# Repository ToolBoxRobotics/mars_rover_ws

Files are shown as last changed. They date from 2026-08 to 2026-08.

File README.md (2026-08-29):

# Mars Rover — ROS 2 Humble Workspace

A 6-wheel, 4-corner-steering Mars exploration rover (Opportunity-style
rocker-bogie steering geometry) with a 5-axis arm, a microscope module
at the 3rd wrist joint, a full sensor suite, Xbox 360 teleop, and a
browser-based ground control console.

**This workspace was rebuilt from scratch** against a new, simplified
hardware spec. It intentionally does not carry over assumptions from
any earlier iteration of this project (e.g. the main perception camera
is now a plain USB/OpenCV webcam per the current spec, not the
previously-selected depth camera — see `rover_description`).

Host OS: Ubuntu 22.04.5 LTS · ROS 2 Humble.

Three documents, three different jobs: **this README** is the
engineering reference (architecture, design decisions, why things are
built the way they are); **`docs/INSTALL.md`** is the one-time
from-scratch build and bring-up guide; **`docs/USER_MANUAL.md`** is
the day-to-day operating guide for a rover that's already built and
running — start-up, driving, arm/mast/microscope controls, and what
the telemetry means.

## Hardware topology

| Board / device | Connects | Controls | ROS package |
|---|---|---|---|
| Arduino Mega #1 | `/dev/rover/base` | 6x drive motor (2x with encoders - see Navigation below), 3x DRI0002 Dual H-Bridge V1.4 (L298N) driver, 4x steering servo via PCA9685 (I2C, address 0x40 - factory default, deliberately unjumpered), 2x FZ0430 voltage sensor (drive rail on A0, steering rail on A1), DS18B20 temperature sensor (1-Wire, pin A4), cooling fan (MOSFET driver module, hardware PWM, pin 44, automatic/thermostatic) | `rover_base` |
| Arduino Mega #2 | `/dev/rover/arm` | 5x NEMA17 + EBA-17-M planetary gearbox (120:1); J1-J3 TB6600, J4-J5 A4988; 5x calibration switch (per-joint configurable homing direction/order/offset - see "Explicit assumptions"); FZ0430 voltage sensor (A0); DS18B20 temperature sensor (1-Wire, pin 20); cooling fan (MOSFET driver module, hardware PWM, pin 44, automatic/thermostatic); latching emergency stop and 3 predefined poses (initial/transport/service) | `rover_arm` |
| Arduino Uno #3 | `/dev/rover/mast` | 2x NEMA17 head yaw/pitch (TB6600 driver, + calibration switches), DC lift (HW-039 driver, erect/stow), 2x lift limit switch, FZ0430 voltage sensor (A0), DS18B20 temperature sensor (1-Wire, pin A4), cooling fan (MOSFET driver module, software PWM, pin A2, automatic/thermostatic) | `rover_mast` |
| Arduino Uno #4 | `/dev/rover/microscope` | DRV8825 + 24BYJ-48 focus/zoom stepper (4-wire bipolar wiring), dimmable LED, SG90 lens cover, DS18B20 temperature sensor (1-Wire, pin 11), cooling fan (MOSFET driver module, hardware PWM, pin 3, automatic/thermostatic) | `rover_microscope` |
| Arduino Uno #5 | `/dev/rover/antenna` | 2x NEMA17 + EBA-17-M planetary gearbox (120:1) + TB6600, high-gain-antenna gimbal (azimuth G1 + elevation G2), 2x calibration switch, FZ0430 voltage sensor (A0), DS18B20 temperature sensor (1-Wire, pin A4), cooling fan (MOSFET driver module, hardware PWM, pin 9, automatic/thermostatic) | `rover_antenna` |
| Arduino Uno #6 | `/dev/rover/power` | 2x INA226 voltage+current monitor (one per 24V battery, behind a TCA9548A I2C mux, A4/A5 - see "Explicit assumptions" for why the mux is needed and a real caveat about current-reading accuracy), DS18B20 temperature sensor (1-Wire, pin 2, monitors the onboard computer, not this board's own enclosure), cooling fan for that computer (MOSFET driver module, hardware PWM, pin 3, automatic/thermostatic). Telemetry-only - no command message, this board controls nothing an operator sends it | `rover_power` |
| Microscope USB camera | `/dev/rover/microscope_cam` | live view, snapshot, recording | `rover_microscope` |
| Main USB camera | `/dev/rover/main_cam` | forward perception (OpenCV) | `rover_sensors` |
| BNO086 IMU (SparkFun Qwiic breakout, UART-RVC jumper mode) | `/dev/rover/imu` (Waveshare USB-TTL (B), CH343G) | orientation + accel, **no Arduino** | `rover_sensors` |
| Waveshare L76X GPS | `/dev/rover/gps` (USB, NMEA0183) | position/velocity, **no Arduino** | `rover_sensors` |
| RPLIDAR C1 | `/dev/rover/lidar` | 360° scan for autonomous nav | external `rplidar_ros` (or `sllidar_ros2`) |
| Xbox 360 controller | USB/wireless receiver | mode-switched drive/arm/mast/microscope teleop | `rover_teleop` (on top of `joy`) |

The last five rows need no Arduino at all — the IMU and GPS modules
free-run straight to a USB-serial adapter, the cameras are plain
UVC/OpenCV devices, and the LIDAR ships its own ROS driver.

All nine serial/video devices are referenced by the stable
`/dev/rover/*` names above; see `rover_bringup/config/udev/99-rover-serial.rules`
for the udev rules that create them, and `tools/identify_rover_devices.py`
for generating them interactively from your own hardware rather than
hand-editing placeholders (including an important caveat about the
three Mega 2560 boards possibly sharing an identical or empty USB
serial number).

These show pin groupings and counts, not exact per-pin schematics —
cross-reference the exact pin constants in each board's `.ino` file
(linked from the hardware topology table above) before wiring, and see
that same file's header comment for power-supply notes (the DRI0002
logic-jumper caveat, servo power needing a separate 5-6V rail, the
lift motor's different dual-direction-pin H-bridge convention) that
don't fit in a pin-level diagram.

## Package map

```
src/
  rover_protocol/     shared checksummed serial framing + SerialLink, used by every bridge
  rover_msgs/         custom interfaces (Base/Arm/Mast/Microscope/Antenna Command+State, BoardStatus, DriveMode) + HomeJoint.srv
  rover_description/  URDF/xacro model (chassis, arm, mast, sensors, solar panels, antenna) + RViz display launch
  rover_base/         Mega #1 bridge: cmd_vel -> 4-corner-steering kinematics -> serial, + wheel odometry
  rover_arm/          Mega #2 bridge: joint-space ArmCommand -> serial, calibration homing, MoveIt trajectory bridge
  rover_arm_moveit_config/ MoveIt2 planning config for the 5-axis arm (SRDF, kinematics, OMPL, controllers)
  rover_mast/         Uno #3 bridge: pan/tilt head (calibration homing) + erect/stow lift -> serial
  rover_microscope/   Uno #4 bridge + USB camera publisher w/ snapshot & recording services
  rover_antenna/      Uno #5 bridge: 2-axis (azimuth/elevation) HGA gimbal -> serial
  rover_sensors/      BNO086 (UART-RVC) IMU driver, L76X GPS driver, main camera publisher
  rover_teleop/       Xbox 360 -> drive/arm/mast/microscope command mapping (built on `joy`)
  rover_web_gui/      FastAPI + WebSocket ground control console (see below)
  rover_navigation/   SLAM (slam_toolbox), sensor fusion + GPS (robot_localization), Nav2 config and launch files
  rover_bringup/      top-level launch file, udev rules, serial-port config
firmware/
  common/RoverProtocol/  Arduino-side counterpart to rover_protocol (install as a library)
  base_mega1/            base_mega1.ino
  arm_mega2/              arm_mega2.ino
  mast_uno3/             mast_uno3.ino
  microscope_uno4/       microscope_uno4.ino
tools/
  validate_workspace.py     syntax/parse sweep (Python/XML/YAML/JS/brace-balance/msg) over the whole tree
  identify_rover_devices.py interactive udev VID:PID/serial capture -> generates 99-rover-serial.rules
  raw_serial_probe.py       ROS-free probe: does a board reply to a raw frame at all? (bypasses rclpy/SerialLink)
```

## Base drive modes

The base supports three steering-geometry modes, selected via
`rover_msgs/DriveMode` on the `rover_base/drive_mode` topic (default
ACKERMANN if nothing has been received yet). `geometry_msgs/Twist` on
`cmd_vel` is reinterpreted differently depending on which mode is
active — see `rover_base/rover_base/kinematics.py` for the exact math.

| Mode | Twist fields used | What it does |
|---|---|---|
| `ACKERMANN` (0) | `linear.x`, `angular.z` | Normal driving — exact ICR-tangent corner steering, front/rear pairs mirror for coordinated arcs |
| `POINT_TURN` (1) | `angular.z` only | Rotate about the rover's own center — forward component forced to zero |
| `STOP` (2) | none (Twist ignored) | Unconditional zero throttle, centered steering |

Both from the Xbox controller (in DRIVE subsystem mode: **X** toggles
ACKERMANN↔POINT_TURN, **Y** forces STOP immediately — see
`rover_teleop/config/xbox_teleop.yaml`) and from the web GUI (mode
buttons at the top of the DRIVE panel, plus a draggable on-screen
joystick for proportional control — see `static/app.js`) publish to
the same topic, so either can drive and either can see what mode is
currently active (`rover_base/command_echo`'s `drive_mode` field is
the ground truth, which both the web GUI's telemetry and — if you
build one — any autonomy stack should read rather than assume).
Both input devices scale stick/joystick deflection by the same
`max_linear_mps`/`max_angular_radps`/`deadzone` values, loaded from
one shared file (`rover_teleop/config/drive_sensitivity.yaml`) rather
than two separately hardcoded copies — see `docs/INSTALL.md` Section
9.4 for how to tune them.

**Hardware caveat, not a bug** (documented in detail as a code comment
on `point_turn_wheel_commands()`): POINT_TURN is bounded by the same
±60° servo limit as ACKERMANN corner steering, so it can't reach a
perfect zero-radius pivot for wheels close to the vehicle's center
(the real angle needed there exceeds 90°) — the achieved motion is the
closest approximation the hardware allows, same limitation already
noted for ACKERMANN's own point-turn-via-zero-forward-velocity case.

## Navigation (SLAM + Nav2 + sensor fusion)

Wheel odometry, IMU/encoder fusion (`robot_localization`), GPS
conversion services, SLAM (`slam_toolbox`), and autonomous navigation
(Nav2) are all wired together. Sensor fusion runs unconditionally as
part of normal bringup (it strictly improves what SLAM/Nav2 already
consume); SLAM and Nav2 navigation are both off by default and
mutually exclusive with each other — build a map first, then navigate
against it, not both at once.

### Architecture

```
encoders (ML, MR) ──┐
                     ├─→ rover_base/odometry_node ─→ wheel_odom ──┐
IMU (BNO086) ────────┼──────────────────────────────────────────┤
                     │                                            ├─→ local EKF ─→ odom (TF: odom → base_link)
                     └────────────────────────────────────────────┘
GPS (L76X) ──→ navsat_transform_node ──→ /odometry/gps (telemetry) + /fromLL, /toLL (services)

slam_toolbox (mapping) or AMCL (navigating) ─→ TF: map → odom
```

- **Wheel odometry** (`rover_base/odometry_node`) reads only the two
  fixed middle wheels (ML/MR) — the only pair whose rolling axis never
  changes with corner steering. See `rover_base/rover_base/odometry.py`'s
  module docstring for the full reasoning. It no longer broadcasts any
  TF itself; it feeds the EKF instead (see below).
- **Local EKF** (`robot_localization`'s `ekf_node`, `rover_navigation/config/ekf_local_params.yaml`)
  fuses that wheel odometry with the BNO086 IMU and becomes the sole
  publisher of the `odom → base_link` TF — smoother and more accurate
  than either sensor alone, which directly improves slam_toolbox's
  scan matching and Nav2's local costmap. Fusion fields are matched
  to what each sensor actually measures rather than a generic
  "fuse-everything" template: wheel odometry contributes velocity
  only (not its own heading estimate, so the IMU's independently
  measured heading corrects drift instead of reinforcing the same
  error twice); the IMU contributes yaw and linear acceleration but
  **not** roll/pitch (redundant under `two_d_mode`, which already
  constrains the filter's own state to zero regardless) or angular
  velocity (the BNO086 in UART-RVC mode doesn't provide it — see
  `bno086_rvc_node.py`).
- **GPS** (`navsat_transform_node`, `rover_navigation/config/navsat_transform_params.yaml`)
  deliberately does **not** feed a second, GPS-fusing "global" EKF —
  that's the common `robot_localization` pattern for outdoor robots,
  but it would fight slam_toolbox/AMCL for ownership of the
  `map → odom` TF (both would try to publish the same edge). Instead
  GPS is used two conflict-free ways: telemetry (`/odometry/gps`, a
  Cartesian rendering of "where GPS thinks the rover is," useful to
  log/compare against the SLAM-based estimate) and **GPS waypoint
  goals** — `rover_navigation/scripts/gps_goal.py` converts a lat/lon
  into the current map-frame position via the `/fromLL` service, then
  sends that straight to Nav2's `navigate_to_pose` action. Nav2 and
  AMCL never need to know GPS was involved at all.
  ```bash
  ros2 run rover_navigation gps_goal.py 42.4373 -86.9436
  ```
  (Needs Nav2 already running against a saved, geo-referenced map —
  the conversion is relative to wherever the datum got set, i.e.
  wherever the rover had a GPS fix when `navsat_transform_node` first
  started.)
- `robot_state_publisher` (already running as part of normal bringup)
  fills in `base_link → ...sensor frames` from the URDF, including
  `base_link → lidar_link`. `slam_toolbox` (while mapping) or Nav2's
  AMCL (while navigating a saved map) supply the remaining
  `map → odom` link — the full chain
  (`map → odom → base_link → lidar_link`) is what lets the LIDAR's
  `/scan` data actually place obstacles on a consistent map.

### Build a map

```bash
ros2 launch rover_bringup bringup.launch.py use_slam:=true
```
Drive the rover around (Xbox teleop or the web GUI) until RViz shows a
complete map, then save it:
```bash
ros2 run nav2_map_server map_saver_cli -f ~/mars_rover_ws/src/rover_navigation/maps/my_map
```

### Navigate autonomously against that map

```bash
ros2 launch rover_bringup bringup.launch.py use_navigation:=true \
    nav_map:=$HOME/mars_rover_ws/src/rover_navigation/maps/my_map.yaml
```
Send goals from RViz (`rover_navigation/rviz/navigation.rviz` has the
"2D Pose Estimate" and "Nav2 Goal" tools already added), via
`ros2 action send_goal /navigate_to_pose ...`, or by GPS coordinate
with `gps_goal.py` above.

### Dependencies

Not vendored in this workspace — see `docs/INSTALL.md`:
`slam_toolbox`, `navigation2`, `nav2_bringup`, `robot_localization`,
`geographic_msgs`. `slam_toolbox`/`navigation2`/`nav2_bringup` are
only actually required at runtime if you pass `use_slam:=true` or
`use_navigation:=true`; `robot_localization` and `geographic_msgs` are
needed unconditionally, since sensor fusion always runs.
`rover_navigation` itself (a lightweight config/launch/scripts-only
package) is always present.

### Not tuned for your environment

`rover_navigation/config/nav2_params.yaml` ships with standard,
reasonable starting values (footprint sized to the rover's actual
wheel extents, velocity limits matching `rover_base`), not something
pre-tuned against your specific space. `ekf_local_params.yaml`'s
process noise covariance is `robot_localization`'s own published
default, not independently re-derived; the measurement covariance
`rover_base/odometry_node.py` publishes on its wheel odometry
(`_TWIST_VARIANCE_*`) is a reasonable placeholder in the same spirit,
not characterized against this rover's actual encoders. Expect to
adjust all three after watching the rover drive and navigate a few
times.

## Arm motion planning (MoveIt2)

Task-space planning for the 5-axis arm (drag an interactive marker to
a target pose, plan a collision-aware path, execute it) via MoveIt2,
off by default (`use_moveit:=false`).

### Architecture

```
RViz "MotionPlanning" panel / any MoveGroupInterface client
        │  plans against the SRDF's "arm" group (shoulder_yaw..wrist_roll)
        ▼
move_group (rover_arm_moveit_config)
        │  planned trajectory (radians), via the FollowJointTrajectory action
        ▼
arm_controller/follow_joint_trajectory ─ rover_arm's trajectory_action_server
        │  converts each waypoint: radians → steps (joint_conversion.py),
        │  reorders to this rover's own joint order (MoveIt doesn't
        │  guarantee its joint_names arrives in that order)
        ▼
ArmCommand (joint_target_steps) ─ exactly what teleop/manual control already sends
        ▼
rover_arm_bridge → 'A' frame → arm Mega #2 → AccelStepper per joint
```

`rover_arm_bridge` and the firmware never change: MoveIt's trajectories
arrive as ordinary `ArmCommand` messages indistinguishable from
teleop's. The bridge between the two — `rover_arm`'s
`trajectory_action_server` — exists specifically because the firmware
already does its own velocity/acceleration profiling on-device
(`AccelStepper`); writing a full `ros2_control` hardware interface
just to satisfy MoveIt's usual execution path would mean reimplementing
that. `moveit_simple_controller_manager`'s `FollowJointTrajectory`
support is built for exactly this case — a robot controller that
already speaks that action interface directly.

Each waypoint is sent as an absolute joint-space target and the bridge
waits until the arm's within tolerance (`goal_tolerance_rad`, default
0.02) or the waypoint's planned time has elapsed, whichever comes
first, before advancing — not a precise replication of MoveIt's planned
velocity profile. Fine for a slow, deliberate sample-inspection arm;
worth knowing if trajectory timing fidelity ever matters more than it
does here.

The `steps_per_joint_rev` calibration (`rover_arm/config/arm_topology.yaml`)
existed as declared-but-unused placeholder data (200 full steps × 1/16
microstepping × 5:1 gear = 16000) since the arm's very first build —
this is what finally puts it to use.

### Using it

```bash
ros2 launch rover_bringup bringup.launch.py use_moveit:=true
ros2 launch rover_arm_moveit_config moveit_rviz.launch.py
```
In RViz's MotionPlanning panel: drag the interactive marker at the
arm's tip to a target pose, **Plan**, check the preview, **Execute**.
Or send a named target — `home` (all-zero, matching the arm's own
homed position) is defined in the SRDF.

The arm must have finished its own startup homing sequence
(`rover_arm_bridge`'s `home_on_startup`, see "How does the calibration
homing sequence work" — `ArmState.homed`) before `trajectory_action_server`
will accept a goal at all; it rejects goals otherwise rather than
commanding an un-homed arm to a fabricated "zero" that isn't real.

### Dependencies

Not vendored — see `docs/INSTALL.md`: `ros-humble-moveit`,
`ros-humble-moveit-configs-utils`. Only required at runtime if you
pass `use_moveit:=true`; `rover_arm_moveit_config` itself (config/launch
only) is always present, matching the same pattern SLAM/Nav2 already use.

## Arm calibration

Each joint's calibration-switch homing can now be triggered on demand
— either individually or all five at once — not just automatically at
bridge startup.

### Architecture

```
Web GUI "CALIBRATE J3" button
        │  POST /api/arm/home/2
        ▼
rover_arm_bridge's rover_arm/home_joint service (rover_msgs/srv/HomeJoint)
        │  validates joint_index locally, writes a 'Z' frame with that index
        ▼
arm Mega #2 → startHoming(2) → seeks J3's limit switch, zeroes it,
              leaves J1/J2/J4/J5's homed status and position untouched
```

`HomeJoint.srv` (`int8 joint_index` in; `bool accepted` + `string
message` out) is this project's first custom service — everything
before this was messages/topics only. `joint_index=-1` homes all 5
joints in one sequential pass (the same behavior `home_on_startup`
has always triggered once at boot); `0`-`4` homes just that one joint,
leaving every other joint's calibration and position alone —
`ArmState.joint_homed` (`bool[5]`) reports this per-joint, not as one
shared flag, precisely so partial calibration is visible rather than
collapsed into a single ambiguous "homed: false".

The service reports whether the request was successfully **written**
to the serial link, not whether the firmware will act on it — that's
a real boundary, not a shortcut: this layer can't see whether the
Arduino, say, silently ignores the request because a homing run is
already in progress. `ArmState.joint_homed` (via `ros2 topic echo
/rover_arm/state` or the web GUI's per-joint ✓/✗ indicators) is the
actual source of truth for whether/when homing completed.

### Deliberate simplification: no partial-homed motion

Every joint must be individually homed — and no homing run in
progress — before **any** joint-move command is accepted, even though
homing itself is now per-joint. A command that moved only the
already-homed joints while silently ignoring the rest would let the
arm move through configurations nothing has actually verified are
safe for the not-yet-homed joint's real position; waiting for a fully
calibrated arm before accepting any motion at all is simpler and
safer. `ArmState.homed` (`bool`) is `all(joint_homed)`, computed by
`rover_arm_bridge` — not sent over the wire, and kept specifically so
MoveIt's `trajectory_action_server` (which already gated goals on this
exact field) needed no changes for this to work.

### Configurable per-joint homing direction and order

Two things about the homing process that used to be a single, uniform
assumption applied to all five joints are now independently
configurable per joint, as constants in `arm_mega2.ino` — both
currently PLACEHOLDER values matching the previous, only behavior,
pending real mechanical verification on the bench:

- **`kHomingDirection[5]`** — which way each joint's stepper seeks
  toward its own limit switch (`+1` or `-1`). Previously a single
  hardcoded `-1` applied to every joint regardless of its own actual
  mechanical layout.
- **`kHomingOrder[5]`** — the sequence joints are homed in during an
  all-5 run (`joint_index=-1`). Previously a fixed J1 → J2 → J3 → J4 →
  J5 loop with no way to change it; a permutation of 0-4, useful for a
  mechanical/safety sequence where one joint genuinely needs to home
  before another (e.g. shoulder before wrist, to avoid a collision
  partway through the sweep). Only affects the all-5 case — a
  single-joint request (0-4) always just homes that one joint,
  unaffected by this order.

Neither is sent over the wire or configurable from the web GUI —
they're physical-calibration facts about the hardware itself, set once
in firmware to match the real joints, not something an operator
chooses per homing run.

### Steps-per-degree, the real lower limit, and the operational range

What this file used to call an "offset" (`kHomingOffsetSteps` — a
small, per-joint, separately-tuned distance from an assumed-zero
switch position to a joint's true reference point) has been replaced
entirely by a physically-grounded model, not just renamed. Three new
constants, none of them invented fresh — all three sourced directly
from numbers this project had already established elsewhere:

- **`kStepsPerDegree[5]`** — derived from, and must be kept in sync
  with, `rover_arm/config/arm_topology.yaml`'s own
  `steps_per_joint_rev` (currently 384000 for all five: 200 full steps
  × 1/16 microstepping × 120:1 EBA-17-M planetary gearbox — see that
  file's own comment). 384000 / 360 ≈ 1066.667 steps/degree.
- **`kMinDeg[5]` / `kMaxDeg[5]`** — each joint's own operational range
  in degrees, relative to true center. Sourced directly from
  `rover_description/urdf/arm.xacro`'s own joint `<limit>` tags
  (shoulder_yaw/elbow_pitch: ±150°, shoulder_pitch/wrist_pitch: ±100°,
  wrist_roll: ±170°) — the same numbers MoveIt itself already plans
  against, not a separately-guessed pair.
- **`kLowerLimitSteps[5]`** — the value assigned via
  `setCurrentPosition()` the instant a joint's limit switch trips. The
  limit switch's own physical trigger point is now understood to sit
  at each joint's own operational lower bound, not at an arbitrary
  "zero" the way `kHomingOffsetSteps` treated it. PLACEHOLDER values
  currently assume the switch sits exactly at `kMinDeg[j]` (converted
  to steps, rounded) — a reasonable starting assumption, not a
  bench-verified one. Kept independently adjustable from `kMinDeg` in
  code (not derived from it), so a real mechanical safety margin
  between "where the switch actually trips" and "the joint's own
  declared operational minimum" can be introduced later without
  touching either constant's own meaning.

Once the switch trips and `kLowerLimitSteps[j]` is assigned,
`serviceHoming()`'s own two-phase state machine (`SEEKING_LIMIT` →
`MOVING_TO_CENTER`, renamed from the old model's `MOVING_TO_OFFSET`
now that the destination is always exactly 0, not a per-joint tuned
value) drives the remaining distance to absolute step 0 using the
normal accel/speed profile — 0 now means each joint's own true center,
not an arbitrary reference point. This is still the same "seek limit,
then move to a real reference position" pattern `mast_uno3.ino`'s and
`antenna_uno5.ino`'s own post-calibration sequences use, just now
landing on a physically meaningful center rather than an arbitrary
offset destination.

**Every regular joint command, and every preset move, is now clamped**
to `[kMinDeg, kMaxDeg]` (converted to steps via `kStepsPerDegree`)
before being accepted — `clampToOperationalRange()`, applied at both
call sites. This is a real, firmware-side backstop, not merely a
courtesy: since MoveIt already plans within these same limits (sourced
from the same `arm.xacro`), this should rarely if ever actually clamp
anything reaching the firmware via a MoveIt-planned trajectory — it
exists for whatever else might reach it: a raw command from the web
GUI's own sliders, a hand-typed test frame, a future client with no
knowledge of these limits at all. The web GUI's own 5 joint sliders
were updated to match these same real bounds (`±160000` / `±106667` /
`±181333` steps) as a UI-side backstop alongside the firmware's own,
replacing an old, disconnected `±16000` placeholder that turned out to
trace back to the same stale 5:1 gear-ratio assumption `arm_topology.yaml`
had already moved past.

**Keeping these numbers in sync matters for a real reason, not just
tidiness**: a mismatch between `arm.xacro`'s own limits and this
firmware's `kMinDeg`/`kMaxDeg` would mean MoveIt could plan a
trajectory this firmware's own clamp then silently truncates — the arm
would quietly stop short of where MoveIt believes it commanded it to
go. There's no automatic single source of truth across the
URDF/firmware/ROS-config/browser boundary here — `arm.xacro`'s own
`<limit>` tags, `arm_topology.yaml`'s own `steps_per_joint_rev`,
`arm_mega2.ino`'s own `kStepsPerDegree`/`kMinDeg`/`kMaxDeg`/
`kLowerLimitSteps`, and the web GUI's own slider bounds are four
separate places carrying related numbers that all need updating
together by hand if any of them ever change.

### Predefined poses

Three fixed five-joint poses — `kInitialPoseSteps`, `kTransportPoseSteps`,
`kServicePoseSteps` in `arm_mega2.ino` — each reachable with a single
`'P'` frame (`rover_arm/arm_preset` service, `rover_msgs/srv/ArmPreset`)
rather than requiring the operator to know and send all 5 target steps
by hand. All three are currently PLACEHOLDER (all-zero, every joint at
its own homed zero) pending real-world calibration — not yet claimed
to be safe, useful, or even reachable poses. Deliberately implemented
as firmware-side constants, addressable by index, rather than computed
or stored at the ROS/web-GUI layer: this way the poses stay reachable
even if the ROS stack is down but the serial link to the Arduino
itself still works, and there's exactly one place these values live
rather than a web-GUI-side copy that could drift from a firmware-side
one. Subject to the same "fully homed, not mid-homing, not e-stopped"
gate as a regular joint command — a preset move is still new movement,
no different from an operator manually driving the sliders as far as
safety gating is concerned.

The web GUI's arm panel exposes these as three buttons (`INITIAL
POSITION`, `TRANSPORT POSITION`, `SERVICE POSITION`) — this **replaced**
an existing button (`RETURN HOME`) that used to send a hardcoded
`[0,0,0,0,0]` directly as a regular joint command, rather than leave
two parallel, potentially-diverging ways to reach a default pose.

## Arm emergency stop

A latching emergency stop, triggered/cleared via a `'X'` frame
(`rover_arm/emergency_stop` service, `rover_msgs/srv/EmergencyStop`) -
`ArmState.estop_active` reports the firmware's own current state.

**Deliberately does NOT de-energize the drivers - a real safety
trade-off, not an oversight.** Conventional e-stop behavior cuts power
to the actuators; this one instead calls `AccelStepper::stop()` on
every joint (a fast, controlled deceleration using each joint's own
configured acceleration - not an instantaneous halt, since forcing an
abrupt step-rate change instead risks the motor losing synchronization
with its driver) and leaves every driver energized throughout. This is
a gravity-loaded arm: de-energizing mid-air risks an uncontrolled
drop, judged worse than holding position under load, the same
philosophy this board's own watchdog-timeout behavior already applies
(and mast/antenna's own watchdogs share).

Once triggered, the e-stop blocks every source of new movement
(regular joint commands, preset requests) until an explicit clear is
received - the firmware itself is the authoritative source of truth
for this, not the ROS bridge node upstream of it, specifically so a
bridge-node restart or hiccup after an e-stop can't silently resume
motion. The web GUI's arm panel exposes this as two buttons (`E-STOP`,
styled distinctly - a solid, high-contrast button rather than this
project's usual outline style, matching real e-stop button
conventions - and `CLEAR E-STOP`), plus a live status readout in the
telemetry panel driven by `estop_active` itself, not by which button
was last clicked - so a page reload or another operator's own action
stays in sync automatically.

### Using it

Web GUI (arm panel): `CALIBRATE J1`-`CALIBRATE J5` for a single joint,
`CALIBRATE ALL 5` for the full sequence, `INITIAL POSITION` to move to
the arm's predefined starting pose (a preset move, not a calibration
action — only meaningful once actually homed, and safely a no-op
otherwise since the firmware ignores it like any other joint command
would be). Driver enable/disable is a single toggle (label and color
both follow the firmware's own reported `drivers_enabled` state, not
a locally-tracked guess) — this brings the arm in line with the same
toggle convention the mast, antenna, and microscope panels already use
for their own driver control; the arm was the one panel still using
two separate buttons for it before this.

Directly:
```bash
ros2 service call /rover_arm/home_joint rover_msgs/srv/HomeJoint "{joint_index: 2}"   # home J3 only
ros2 service call /rover_arm/home_joint rover_msgs/srv/HomeJoint "{joint_index: -1}"  # home all 5
```

## Antenna gimbal

A 2-axis high-gain-antenna pointing mechanism, top rear left of the
rover, modeled on the real Mars Exploration Rover (Spirit/Opportunity)
HGA gimbal — G1 (azimuth, primary axis, normal to the deck) and G2
(elevation, secondary axis, parallel to the deck), with the antenna
disk on a short arm at the end and the beam radiating perpendicular to
the disk face.

### Real-hardware research behind this

The spec for this subsystem gave two different ranges per axis: G1
`[-90°, 90°]` / G2 `[90°, 270°]`, and — specifically for the
*deployed* configuration — g1 `[15°, 285°]` / g2 `[0°, 180°]`
("software-limited"). Those two pairs don't reconcile numerically as a
simple offset (180° span vs. 270° span for azimuth), so before
building anything, this was checked against the real MER HGAG
engineering paper (Sokul et al., ESMATS 2004) rather than guessed at.
That paper confirms the real mechanism: a pyrotechnic-released,
one-way spring-gate deployment (the drive "can no longer return to the
original stowed position" once through the gate), with **280° azimuth
and 234° elevation** as the real, published post-deployment rotation
spans — closely corroborating g1's 270° span and confirming g2's 180°
is a deliberate *software* restriction of what's mechanically possible
(real elevation capability is 234°), matching this project's own
"software-limited" framing exactly.

**g1 `[15°, 285°]` and g2 `[0°, 180°]` are what's implemented and
enforced** (`antenna_uno5.ino`'s `constrain()` calls,
`antenna_topology.yaml`'s `min/max_azimuth_deg`/`min/max_elevation_deg`).
G1/G2 (uppercase) reads as a different reference frame — not
reconciled into a second active constraint here, since doing so would
require guessing at a transformation the source material doesn't
specify. Flagged here rather than silently picked one interpretation.

### What's modeled and what isn't

Only the two gimbal axes' *operational* range is implemented — there's
no launch-lock, pyrotechnic pin puller, or deploy-gate mechanism
modeled (out of scope for what was asked: 2 stepper axes + calibration
switches, not a deployment sequencer). The antenna is treated as
already deployed for all purposes here.

Each calibration switch is assumed mounted at that axis's own
operational **minimum** (15° azimuth, 0° elevation) — a real design
choice, not verified against an actual mechanical drawing, flagged
here and in `antenna_uno5.ino`'s header comment so it's easy to
correct against real hardware. This makes homing simpler than the
mast's: the switch position *is* each axis's minimum, not offset from
a separately-centered zero, so `setCurrentPosition()` at trigger time
directly establishes "home" — no follow-on move-to-a-different-
reference step the way the mast's own (corrected) calibration sequence
needs one.

### Hardware

Same actuator/driver combination as the arm's joints — 2x NEMA17 +
EBA-17-M planetary gearbox (120:1) + TB6600, on an Arduino Uno with 2
calibration switches and an FZ0430 voltage sensor. `steps_per_deg`
and the speed/acceleration/homing-speed constants in `antenna_uno5.ino`
are copied directly from `arm_mega2.ino` rather than re-derived — same
actuator, already-vetted numbers. The two TB6600 drivers share one
enable pin (`kGimbalEnablePin`), safe for the same reason the mast's
own two TB6600s share one: two opto-isolated ENA inputs draw
comfortably under a typical GPIO's safe sink rating, unlike the arm's
three TB6600s, which get independent pins instead.

### Using it

Web GUI (antenna panel): azimuth/elevation sliders (range fetched from
`antenna_topology.yaml` via `GET /api/config`, same mechanism the
mast's transport-position preset uses) and a `CLOSE DRIVER (ENABLE)` /
`OPEN DRIVER (DISABLE)` toggle — starts disabled after homing, same
convention as the mast, until explicitly enabled.

Xbox controller (LB until in ANTENNA mode): left stick jogs azimuth
(X) and elevation (Y) from the current position, rather than an
absolute-position mapping the way the mast's right stick works — the
antenna's operational range isn't centered around 0° the way the
mast's is, so mapping stick deflection straight to an absolute angle
would be a much less natural control feel here.

## Explicit assumptions and simplifications

These are the calls made where the spec was silent or where
"simplify" pointed toward a lighter-weight choice. Flag any of these
back if they don't match the real hardware:

- **Arm: driver-enable state is now real telemetry, not just a
  command the host remembers sending - and the web GUI's own button
  for it changed from two to one to match.** `arm_mega2.ino`'s own
  `driversEnabled` was already tracked internally; it just never made
  it into the outgoing `'S'` frame, so the only place that state
  existed was whatever the host last commanded via the `'A'` frame's
  own `enable` field. That gap was real, not hypothetical:
  `startHoming()` enables drivers automatically before seeking, with
  no operator action involved, so a value the web GUI only remembered
  sending would have silently drifted out of sync with reality the
  moment homing started on its own. Added `drivers_enabled` as a new,
  20th field on the `'S'` frame (threaded through the protocol layer,
  `ArmState.msg`, the bridge node, and the web GUI's own state dict) so
  this is now the firmware's own actual, current state, always - not a
  command echo.

  The web GUI's own two separate buttons (`ENABLE DRIVERS` /
  `DISABLE (FREE-SPIN)`) became one toggle, at the user's own explicit
  request - and this turned out to be less a departure from this
  project's own convention than a correction of one: the mast, antenna,
  and microscope panels already use a single `CLOSE DRIVER (ENABLE)` /
  `OPEN DRIVER (DISABLE)` toggle for the exact same kind of state; the
  arm was the one panel still using two separate buttons for it. Kept
  the arm's own, more explicit wording (`ENABLE DRIVERS` /
  `DISABLE DRIVERS (FREE-SPIN)`, the button's own label switching with
  the state rather than the other three panels' `CLOSE`/`OPEN`
  phrasing) since the free-spin consequence is a genuinely useful thing
  to say out loud for a 5-joint arm specifically, not just tidied away
  for consistency's sake - the toggle *mechanism* is what needed to
  match, not necessarily the exact words. The button's label and color
  both follow `data.arm.drivers_enabled` from live telemetry on every
  render, the same "driven by the firmware's own reported state, not a
  locally-tracked guess" approach already used for this panel's own
  E-STOP status readout.

  Verified this compiles cleanly against the real toolchain before
  calling it done, not just reviewed by eye: installed the actual AVR
  cross-compiler (`gcc-avr`, matching the Arduino IDE's own
  Atmel-flavored 7.3.0) plus `ArduinoCore-avr`, `AccelStepper`,
  `OneWire`, and `DallasTemperature` from their real source
  repositories, and compiled `arm_mega2.ino` with `-Wall` - zero
  errors, zero warnings, both before and after this session's own
  change to `sendStateFrame()`.

- **Arm: a physically-grounded homing/coordinate model replacing an
  arbitrary one, and a real operational-range clamp - sourced from
  numbers this project had already established, not invented fresh.**
  Full technical detail lives in "Arm calibration" above (see
  "Steps-per-degree, the real lower limit, and the operational range");
  this entry is about the sourcing decision itself, which is the part
  most worth flagging back if it's wrong.

  Rather than invent placeholder degree/range numbers the way most of
  this project's other uncalibrated constants default (all-zero, or
  "matches the previous behavior exactly"), this instead reused two
  sets of numbers this project already had on record before this
  session touched anything: `rover_arm/config/arm_topology.yaml`'s own
  `steps_per_joint_rev` (384000, already correctly reflecting the
  120:1 gearbox) for `kStepsPerDegree`, and
  `rover_description/urdf/arm.xacro`'s own joint `<limit>` tags (±150°/
  ±100°/±150°/±100°/±170°) for `kMinDeg`/`kMaxDeg` - both were real,
  specific, already-intentional values, not placeholders themselves,
  so treating them as placeholders here and inventing different
  numbers would have created a genuine inconsistency (MoveIt planning
  against one set of limits while the firmware clamped against
  another) rather than resolved one. `kLowerLimitSteps` (what the
  limit switch's own trigger point gets labeled as) uses the same
  numbers as `kMinDeg`, converted to steps, as its own placeholder -
  physically reasonable (switch mounted right at the operational
  minimum) but not itself bench-verified, and kept as an independently
  adjustable constant rather than computed from `kMinDeg` in code, so
  a real mechanical margin between the two can be introduced later
  without changing what either constant means.

  Found and fixed two genuine, unrelated staleness issues while
  sourcing these numbers, both traced to the same root: a stale 5:1
  gear-ratio assumption (200 full steps × 1/16 microstepping × 5:1 =
  16000) that predated this project's move to the real 120:1 EBA-17-M
  gearbox (384000) but was never fully swept away. `joint_conversion.py`'s
  own module docstring still cited the old 16000 figure; the web GUI's
  5 joint sliders still used a `±16000` bound that turned out to be
  exactly one motor revolution's worth of steps at that same old ratio
  - both fixed, the sliders updated to the real, `arm.xacro`-derived
  bounds (`±160000`/`±106667`/`±181333` steps) as a UI-side backstop
  alongside the firmware's own new clamp, not a replacement for it.

  A historical "Explicit assumptions" bullet from an earlier session
  (this file's own "Calibration direction, order, and post-limit-
  switch offset..." entry, further below) referenced
  `kHomingOffsetSteps` by name - since that constant no longer exists,
  updated that entry in place to redirect here rather than leave it
  factually describing code that isn't there anymore.

- **The actual root cause of base/arm never showing telemetry in the
  web GUI - found only after ruling out the firmware, the physical
  serial link, and the ROS topic layer entirely, each independently
  confirmed healthy first.** `rover_web_gui/ros_bridge.py`'s own
  `_on_base_state()`/`_on_arm_state()` callbacks converted fixed-size
  ROS array fields (`BaseState.encoder_ticks`/`encoder_delta_ticks`,
  `ArmState.joint_position_steps`/`limit_switch_triggered`/
  `joint_homed`) with a bare `list(msg.field)`. rclpy backs every
  fixed-size array message field with `numpy.ndarray` internally, so
  `list()` on one produces `numpy.int32`/`numpy.bool_` elements, not
  plain Python `int`/`bool` - and `json.dumps()` cannot serialize
  either numpy scalar type at all; it raises `TypeError` unconditionally.
  Reproduced directly, not just reasoned about: `json.dumps([numpy.int32(1)])`
  raises `TypeError: Object of type int32 is not JSON serializable`,
  confirming the mechanism exactly.

  **Why this took multiple sessions and several ruled-out hypotheses
  to actually find, rather than being obvious from the symptom
  alone:** `server.py`'s own `_telemetry_sender()` builds one combined
  snapshot for every board and serializes it in a single `json.dumps()`
  call inside one `asyncio` task, previously with no exception handling
  of its own around that call. An uncaught exception in an `asyncio`
  task doesn't crash the process - it just silently stops that task,
  logged only as "Task exception was never retrieved" server-side, with
  nothing the browser's own console would ever show (which is exactly
  why a browser dev-tools check came back completely clean - the
  failure never reached the browser to produce an error there in the
  first place). Every board's telemetry rode on that same one task and
  one combined snapshot, so base or arm's own bad array field silently
  killed telemetry for every board at once, not just its own - mast,
  microscope, antenna, and power *looked* like they still worked only
  because the browser kept displaying whatever their own last
  successfully-sent values had been, frozen, from before the task died;
  they were never actually still updating. Base and arm are also the
  *only* two boards whose own state messages contain any array field at
  all - checked directly against every board's own `.msg` file, not
  assumed - which is why this affected exactly and only those two,
  matching the actual reported symptom precisely.

  Fixed with an explicit per-element cast at both call sites
  (`[int(t) for t in ...]`, `[bool(t) for t in ...]`) rather than a
  generic serialization workaround, matching the same fix already
  applied once before to this exact bug class in a different file
  (`arm_bridge_node.py`'s own `_on_timer()`, from an earlier session) -
  a second, independent occurrence of the same underlying rclpy
  behavior, not a regression of the first fix. Also hardened
  `_telemetry_sender()` itself with its own per-tick exception handling
  around the send, specifically so a future, different field with the
  same problem can't silently take down every board's telemetry again
  the same way - it now logs clearly and skips that one tick instead of
  dying for the rest of the connection's lifetime.

- **A real, project-wide bug found via a live log capture, not code
  review: `SerialLink` could hang a bridge node's entire executor
  thread indefinitely on a single write, with no error and no further
  log output at all.** `rover_protocol/serial_link.py`'s underlying
  `serial.Serial` connection was constructed with a read `timeout`
  but no `write_timeout` - pyserial's own default when that's left
  unset is `None`, meaning a write blocks forever if the OS-level
  output buffer fills and the board on the other end isn't draining
  its own serial RX fast enough to keep up. This is shared
  infrastructure every bridge node (base, arm, mast, microscope,
  antenna, power) is built on, so the exposure was project-wide, not
  specific to any one board - but the arm was the one that actually
  hit it during testing, and for a specific, identifiable reason: its
  homing sequence legitimately runs far longer than this project's
  usual command-response turnaround (a 120:1 gearbox slows real joint
  motion, and `serviceHoming()`'s own seek phase doesn't yield back to
  frame handling as promptly as a quick command-and-respond cycle
  does), during which the bridge node's own continuous, periodic
  writes kept arriving while the firmware wasn't getting back around
  to draining its input quickly enough - eventually filling the
  board's tiny 64-byte hardware RX buffer and blocking the write call
  forever.

  **Diagnosed from an actual log capture, after code review alone had
  been exhausted without finding it** - a user-provided log showed the
  arm bridge node logging "sent homing request to arm Mega" and then
  going completely silent forever, no error, no crash, no further
  output of any kind - the exact signature of a thread stuck on a
  blocking syscall, not a program error, which produces neither. Since
  `_publish_status()` sits after the write call in the same function,
  a hung write there meant `BoardStatus` was never published even
  once - explaining a status lamp stuck at its default "never
  received" state (which reads as red) rather than a lamp that turns
  green and then goes stale, and why the arm specifically was the
  board most likely to actually trigger this given its own homing
  duration, even though the underlying vulnerability was never
  arm-specific at all.

  Fixed with a bounded `write_timeout` (defaulting to 0.2s, matching
  the existing read timeout's own general magnitude) threaded through
  `SerialLink`'s constructor to the underlying connection - a write
  that can't complete now raises `serial.SerialTimeoutException`,
  caught by the same exception handler every other write failure
  already goes through, rather than hanging the calling thread
  indefinitely. Verified every one of the six bridge nodes constructs
  `SerialLink` using keyword arguments exclusively before considering
  this fix backward-compatible - none needed any changes themselves,
  since a purely-keyword call site can't be affected by a new
  parameter's position in the signature. Two dedicated regression
  tests confirm `write_timeout` is actually threaded through to the
  underlying connection, not just accepted and silently dropped, and
  that it defaults to a real, bounded value rather than the `None`
  that was the root cause here.

- **Arm: a latching emergency stop, and calibration made independently
  configurable per joint where it used to be a single hardcoded
  assumption applied to all five.** Also found and fixed a real
  documentation gap while updating this table: the arm's own cooling
  fan (present in firmware for several sessions) had never made it
  into this hardware topology row at all.

  **Emergency stop deliberately does NOT de-energize the drivers - a
  real, non-obvious safety trade-off, not an oversight.** Conventional
  e-stop behavior cuts power to the actuators; this one instead calls
  AccelStepper's own `stop()` on every joint (a fast, controlled
  deceleration using that joint's own configured acceleration, not an
  instantaneous halt - forcing an abrupt step-rate change instead
  risks the motor losing synchronization with its driver, arguably a
  worse outcome than a fast but controlled stop) and leaves every
  driver energized throughout. This is a gravity-loaded arm: de-
  energizing mid-air risks an uncontrolled drop, which this project has
  already judged worse than holding position under load in the
  near-identical watchdog-timeout situation this same board's firmware
  already had (and mast/antenna's own watchdogs share the same
  philosophy). Once triggered, the e-stop is latching and blocks every
  source of new movement (regular joint commands, preset requests)
  until explicitly cleared - the firmware itself is the authoritative
  source of truth for this state, not the ROS bridge node upstream of
  it, specifically so a bridge-node restart or hiccup after an e-stop
  can't silently resume motion.

  **Calibration direction and order are now independently configurable
  per joint, as PLACEHOLDER firmware constants** (`kHomingDirection`,
  `kHomingOrder` in `arm_mega2.ino`) pending real mechanical
  verification on the bench - each currently set to match the
  previous, only behavior (uniform direction, sequential J1-J5 order)
  rather than a guessed-at "improved" default.

  **UPDATE (later session): the post-limit-switch "offset" this bullet
  originally described here has since been replaced entirely, not
  merely adjusted** - `kHomingOffsetSteps` no longer exists.
  `kLowerLimitSteps`, `kMinDeg`/`kMaxDeg`, and `kStepsPerDegree` took
  its place, along with a firmware-side clamp on every joint command
  and preset move - see "Steps-per-degree, the real lower limit, and
  the operational range" above for the complete, current model; not
  duplicated here to avoid two descriptions drifting apart from each
  other over time.

  **Three predefined poses (initial/transport/service), reachable via
  a new firmware-level command, not just a web-GUI convenience.** All
  three are ALL-PLACEHOLDER (all-zero, every joint at its own homed
  zero) pending real-world calibration - not claimed to be safe,
  useful, or even reachable poses yet. Deliberately implemented as
  fixed constants in `arm_mega2.ino` itself, addressable by index over
  the wire, rather than joint angles computed or stored at the ROS/
  web-GUI layer - this way the poses stay reachable even if the ROS
  stack is down but the serial link to the Arduino itself still works,
  and there's exactly one place these values live rather than a
  web-GUI-side copy that could drift from a firmware-side one. This
  **replaced, rather than duplicated, an existing endpoint**: the web
  GUI already had a "RETURN HOME" button sending a hardcoded
  `[0,0,0,0,0]` directly - upgraded to call the new firmware-owned
  INITIAL preset instead of leaving two parallel, potentially-
  diverging ways to reach a default pose. The "SERVICE" pose's actual
  intended purpose (what it needs to clear or reach) wasn't specified
  further when this was added - kept as a generically-named preset
  pending that detail, rather than guess at a real value without
  knowing what it's actually for.

- **Microscope: the LED/cover "protect the optics" fail-safe is
  removed entirely, at the user's own explicit request - a genuine
  safety trade-off, not a cosmetic change, worth stating plainly
  rather than folding into a routine changelog line.** Two
  independent implementations of the same behavior existed - the
  firmware's own watchdog (`microscope_uno4.ino`'s `loop()`, forcing
  the LED off and the cover closed whenever no command had arrived
  for over a second) and the bridge node's own parallel version at
  the ROS layer (`microscope_bridge_node.py`'s `_on_timer()`, forcing
  the same values into every command frame it sent whenever the ROS
  command stream itself went stale) - both found and removed
  together; removing only one would have left the other silently
  reintroducing the exact behavior being removed; the firmware has no
  way to distinguish a genuine operator command from the bridge
  node's own override.

  **What this actually means**: the LED and cover now stay in
  whatever state they were last explicitly commanded to,
  indefinitely, even if the serial link between the bridge node and
  the Uno drops, or the ROS command stream from the web GUI stops
  entirely. Previously, either kind of link loss would have
  automatically turned the LED off and closed the cover within about
  a second. **If the LED is left on or the cover left open when a
  link drops now, nothing in this software will turn it off or close
  it on its own** - that's on the operator (or whatever's upstream)
  to notice and handle. The focus stepper was never part of this
  fail-safe either way - it already just holds its last commanded
  position on a dropped link, with no separate timeout logic of its
  own, unaffected by this change.

  Removed cleanly, not just disabled: `kWatchdogTimeoutMs`/
  `lastCommandMillis` in the firmware, `command_timeout_sec`/
  `_last_command_time` (and the now-unused `time` import) in the
  bridge node, and the `command_timeout_sec` config parameter in
  `microscope_topology.yaml` are all gone, not left declared-but-
  unused - a note in that yaml file explains the parameter's absence
  explicitly, since every other board's own config still has one and
  its absence here could otherwise look like an oversight rather than
  a deliberate choice.

- **Microscope: most of a multi-part request turned out to already be
  done, verified rather than assumed.** Asked for: remove ServoEasing
  from the cover servo, add explicit OPEN/CLOSE cover buttons, add
  explicit LED ON/OFF buttons, and express LED dimming in 0-5V rather
  than raw PWM. Checked the actual current state of each part before
  doing any work rather than trust memory of what had been built: the
  ServoEasing removal (firmware header explicitly records it as
  already done "at the user's own request"), the cover buttons, and
  the LED on/off buttons were all already fully implemented and wired
  up, in both `app.js` and `index.html`. Only the 0-5V display change
  was genuinely outstanding.

  **The LED change is display-only, not a wire-protocol or hardware
  change** - the microscope's LED is still driven by plain
  `analogWrite()` PWM (0-255 duty cycle), not a true analog output or
  DAC; nothing in the request mentioned new hardware to enable one.
  0-255 duty cycle on a 5V logic pin genuinely *is* 0-5V of effective
  average output, so relabeling the existing range this way is
  accurate, not approximate. Changing the wire protocol itself to
  carry millivolts would have meant a firmware-side conversion back to
  PWM for no real gain, and could misleadingly imply a precision the
  hardware doesn't actually have - so `led_pwm` stays exactly what it
  was (0-255) all the way from the slider's own raw value through the
  wire protocol to `analogWrite()`; only the label the operator sees
  changed, via a small shared `formatLedVoltage()` helper used
  consistently by the slider, both buttons, and the telemetry panel's
  own LED readout, rather than four separate copies of the same
  conversion.

- **Base: a second FZ0430, splitting one shared voltage reading into
  two independent rail readings.** Requested as "add a second FZ0430
  with the same configuration... designate the first for driving
  current and the second for steering current" - the FZ0430 measures
  voltage, not current, so this was confirmed rather than guessed at
  before any code changed: the user's own follow-up, "I confirm my
  mistake; I meant the voltage capture," settled it as two voltage
  rails, not current sensing (which would have meant a different part
  entirely, like the ACS712 or INA226 already used elsewhere in this
  project).

  The existing FZ0430 (A0) is now explicitly the **drive** motors' own
  supply rail - previously just a generic "main supply" reading, since
  there was only ever one rail to report before this. A second,
  identically-configured FZ0430 (A1, same 5:1 divider, same conversion
  math) reports the **steering** servos' own supply rail. This is a
  genuine rename, not just an addition: `BaseState.msg`'s
  `supply_voltage_mv` became `drive_voltage_mv`, with `steering_voltage_mv`
  added alongside it - every layer (firmware, protocol, message,
  bridge node, web GUI) updated together for the rename, not just the
  new field, including proactively checking `ros_bridge.py`'s own
  state-capture callback before it could become another instance of
  the same bug class prior sessions have repeatedly found there.

  Two other pre-existing, unrelated staleness issues were caught and
  fixed while working in this same firmware section: `base_protocol.py`'s
  own 'D' frame docstring still said steering was sent to "direct Mega
  pins A4-A7, no PCA9685," despite that migration happening several
  sessions ago; and the voltage section's own top-of-block comment
  still said "voltage sensor" (singular) after this session's own
  second sensor was added, missed in an earlier pass through the same
  edit. Fixed both rather than let stale text stand next to newly
  correct code.

- **Board-status lamps could never actually show a "connected but
  receiving garbage" state, on any board, until now** — found while
  investigating a report of missing power-panel telemetry. The green
  lamp's own meaning had been misleading the whole time: `connected`
  becomes `true` the moment a serial port opens successfully,
  completely independent of whether any valid frame has ever been
  received - that's a separate counter (`rx_frame_count`) entirely.
  A three-state helper function (`boardStatusPillClass()`, fault/
  warn/ok) already existed in `app.js`, correctly written, but was
  never actually called anywhere - the real lamp-rendering loop used
  a simpler connected-only check instead, so a board silently
  producing nothing but checksum errors (most plausibly a `/dev/rover/X`
  symlink resolving to the *wrong* physical device - a real risk
  anywhere two boards share a VID:PID; `power_uno6` now shares this
  risk with mast, microscope, and antenna, all four genuine Unos
  reporting the identical 2341:0043, see that board's own bullet
  above for the history) would show exactly the same
  plain green as a board that's genuinely working, with nothing to
  visually distinguish the two.

  Wired the existing function into the actual rendering loop, added
  the missing CSS for the state that never had it (`--amber`, already
  an established color in this project's palette, reused rather than
  introducing a new one), and surfaced `checksum_error_count`
  directly in the lamp's own meta text (e.g. "12 rx, 340 bad") so the
  distinction is visible without needing to check a ROS topic
  directly. This applies to every board in the project, not just the
  one whose report surfaced it - any board that's ever been "green
  but not actually working" was experiencing exactly this same gap.

- **`power_nano6.ino` failed to compile in the Arduino IDE: "error:
  'BatteryReading' does not name a type" — a real, documented
  Arduino toolchain bug, not a mistake in the code as written.** The
  struct itself was correctly defined, with its semicolon, before its
  first use - reading the file top to bottom, a human would see
  nothing wrong. The actual cause: the Arduino IDE/arduino-cli
  automatically generates forward declarations (prototypes) for every
  function in a sketch and inserts them immediately after the file's
  `#include` lines, *before* any type declared later in the file -
  including a custom struct that's fully defined earlier than the
  function using it, from the actual source file's own perspective.
  This is a known, long-open toolchain issue (see
  `arduino/arduino-cli#2696` and `arduino/Arduino#8014`/`#8050`, the
  oldest reports going back over a decade), not specific to this
  project or this session's code.

  Fixed by removing the custom `BatteryReading` struct entirely and
  rewriting `readBattery()` to use output parameters
  (`int32_t &voltageMv, int32_t &currentMa`) instead of returning a
  struct by value - every type in the function's signature is a
  built-in type already known before any auto-generated prototype
  could need it, so there's nothing left for the toolchain's ordering
  bug to trip over. The officially documented workaround (move the
  struct to a separate header file, since the auto-prototype step
  only scans the `.ino` file itself) was available too, but would
  have introduced a multi-file sketch structure no other board in
  this project uses - the output-parameter rewrite fixes the same
  problem while keeping every board's firmware a single, self-
  contained file.

  Swept every other firmware file afterward for the same pattern (any
  custom `struct`/`enum` used as a function parameter or return type,
  not just declared for local variables) rather than assume this was
  an isolated case - found none; every `enum` elsewhere in this
  project is only ever used for `int8_t`-typed variables and their
  own enumerator constants, never in a function signature, so none of
  them were ever at risk of this same failure.

- **New subsystem: power/environmental monitoring, board #6** — two
  24V batteries' own voltage and current, onboard computer
  temperature, and that computer's automatic cooling fan. The sixth
  board in this project, and structurally different from the other
  five: it has no command message at all. Every other board's
  bridge node sends commands and receives state in response; this
  one only ever receives, since there's nothing for an operator to
  command here - both sensors are read-only and the fan is fully
  automatic, matching every other fan in this project. The firmware
  proactively sends its own state frame every ~200ms rather than
  reactively, in response to an incoming command, the way every
  other board's `sendStateFrame()` is triggered - see
  `power_uno6.ino`'s own header comment for the reasoning.

  **UPDATED: the original FZ0430 + ACS712 sensor suite was replaced
  with two INA226 voltage+current monitors behind a TCA9548A I2C
  multiplexer**, after the FZ0430's real safety concern (a hard 25V
  ceiling that a nominal 24V pack could plausibly exceed in normal
  operation - see the earlier version of this bullet's own history
  in `docs/journal.md` for the full original reasoning) led to a
  direct recommendation for the INA226 instead: its 0-36V bus range
  gives genuine headroom above the ~28-29V worst case a 24V pack can
  realistically reach, not a replaced-but-still-tight margin. This
  also gives each battery its own current reading for the first
  time, rather than the single ACS712's combined draw across both -
  a real, if secondary, improvement that fell out of the switch
  rather than the primary reason for it.

  **Why a TCA9548A multiplexer, given the INA226 already supports 16
  addresses via its own A0/A1 pins**: both INA226 units in this
  design sit at their shared, unmodified default address (0x40, both
  address pins grounded) - the mux is specifically what makes two
  identical, off-the-shelf breakouts workable together on one bus,
  without needing to reconfigure either one's address pins. The mux
  itself defaults to 0x70, unjumpered - see the next bullet for why
  that number specifically needed its own explicit callout.

  **0x70 now appears in this project for two unrelated reasons, on
  two physically separate boards** — the PCA9685's own built-in "All
  Call" address on the base board (see that bullet above), and now
  the TCA9548A's own default address on the power board. These don't
  conflict with each other in any way - separate chips, separate
  Arduinos, separate I2C buses - but 0x70 has already caused one
  real, documented confusion in this project (an earlier session
  mistakenly jumpered a PCA9685 *toward* 0x70, precisely the address
  that should never be a device's primary one), so a second,
  unrelated appearance of the same number is named explicitly here
  and in `power_uno6.ino`'s own header, rather than left as a
  coincidence someone has to notice on their own later.

  **A real, must-verify hardware concern, not routine calibration**:
  the INA226 measures current via the voltage drop across an
  external shunt resistor, and its own shunt-voltage measurement
  range is hard-capped at ±81.9mV. Many generic INA226 breakouts ship
  with a fixed, onboard 0.1Ω shunt - with that value, the *maximum*
  current such a board could ever report before its shunt voltage
  saturates is 81.9mV / 0.1Ω ≈ 0.82A, far below what this rover's
  batteries actually need to measure (the ACS712 this replaced was
  rated for 30A). `kInaShuntOhms` in `power_uno6.ino` is set to
  0.002Ω - a smaller, higher-current-range value some INA226
  breakouts use specifically for this reason - as a placeholder, not
  a verified fact about the actual boards in hand. **Check what
  shunt resistor your specific breakout boards actually have before
  trusting any current reading beyond a rough one** - if readings
  clip at a suspiciously round, low number regardless of real load,
  this is almost certainly why, not a firmware bug.

  Library: **INA226** (by Rob Tillaart, MIT licensed) - confirmed
  directly from the library's own repository page, not assumed. No
  dedicated library for the TCA9548A itself: channel selection is a
  single I2C write of one byte (`Wire.beginTransmission(0x70);
  Wire.write(1 << channel); Wire.endTransmission();`), simple enough
  that a library would add a dependency for less code than it saves,
  the same reasoning this project has applied to other single-purpose
  I2C writes elsewhere.

  **UPDATED: this board is now an Arduino Uno, not a Nano.** Swapped
  after repeated, unresolved hardware trouble with the Nano units in
  hand - the user's own words, "with which we have often had
  difficulties," without a single, isolated root cause identified
  (the missing-telemetry investigation two sessions ago found the
  code correct at every layer; the compile error before that was a
  genuine Arduino toolchain bug, not the board's fault - neither
  incident actually indicts the Nano hardware itself, but repeated,
  hard-to-pin-down trouble with a specific batch of units is a
  legitimate reason to just swap them, whether or not any single
  session's root cause was ever conclusively the board). No pin
  reassignment was needed for the swap: the Nano and Uno share the
  same ATmega328P, the same D2-D13 digital range, the same
  D3/D5/D6/D9/D10/D11 PWM pins, and the same A4/A5 I2C pins - every
  pin this board's own firmware actually uses. The Nano's two bonus
  analog-only pins (A6/A7), which the Uno lacks, were never used by
  this board's sensor suite either way, so nothing was lost.

  **The CH340-clone-vs-GPS-adapter USB collision risk from the
  original Nano build is retired by this swap, not carried forward**
  - that risk was specific to the Nano's own USB-serial chip
  situation (a genuine FTDI-based Nano vs. a common CH340-based clone
  reporting completely different VID:PIDs). **A different, but
  already-documented and already-understood, collision risk takes
  its place**: this board now reports the same VID:PID (2341:0043)
  as every other genuine Arduino Uno in this project. Found while
  updating the udev rules for this swap that this was actually a
  *fourth* instance of that exact situation, not a third - mast,
  microscope, and antenna were already sharing this VID:PID, but an
  earlier version of the mast's own udev entry had a real, separate,
  previously-uncaught bug: it matched `idProduct` `0042` (the Mega's
  ID) with a placeholder literally named `MAST_MEGA_SERIAL`, left
  over from before the mast itself became an Uno many sessions ago.
  As written, that rule could only ever have matched base's or arm's
  own Mega - never the mast's actual hardware. Fixed alongside this
  session's own change, not left standing next to it.

- **Arm: a real driver-enable race condition, found while answering a
  question about the state machine's behavior, not while looking for
  bugs specifically.** `arm_mega2.ino`'s `handleJointCommand()` used
  to call `setDriversEnabled(enable)` unconditionally, before its own
  `homed`/`homingInProgress` gate - `mast_uno3.ino`'s and
  `antenna_uno5.ino`'s equivalent handlers already gate this
  correctly (`setGimbalEnabled`/`setHeadEnabled` only inside `if
  (homed)`), a fix built specifically to prevent this exact problem
  several sessions ago on those two boards. The arm's own handler
  predates that fix and never received the equivalent treatment.

  `arm_bridge_node.py` sends 'A' frames continuously at its own
  control rate, including while homing is in progress - by design,
  and normally harmless, since the frame's `enable` field is meant to
  be ignored during homing. But with the gate in the wrong place, it
  wasn't ignored: the bridge's own default (`enable=False`, until an
  operator has actually touched the arm panel) meant every regular
  frame arriving mid-homing would immediately undo the `enable=true`
  `startHoming()` had just set. On a real, previously-untouched boot,
  this meant the drivers could be toggled enabled (once, by
  `startHoming()`) and disabled (repeatedly, by every regular frame
  arriving during the entire seek) throughout homing - not just an
  inert flag flipping back and forth, but the physical drivers
  actually losing power while `AccelStepper` kept counting step
  pulses as if they'd been executed, risking the exact kind of
  position-tracking corruption per-joint homing exists to establish
  in the first place.

  Fixed by moving `setDriversEnabled()` inside the same gate the
  joint-target application already used, matching mast/antenna's
  pattern exactly rather than inventing a new one. Also corrected the
  bridge node's own comment, which had asserted the firmware already
  handled this correctly - it didn't, and a comment describing
  intended behavior as already-true is worse than no comment once
  it's wrong.
- **Microscope's driver enable/disable button never actually worked,
  since the day it was built — the other three (mast, antenna, arm)
  did, and were verified to, not assumed to.** Reported as "enable/
  disable doesn't physically work" without specifying which
  subsystem, so every driver-enable path got checked end to end
  (web GUI → `server.py` → `ros_bridge.py` → bridge node → wire
  protocol → firmware) rather than guessed at: arm's, mast's, and
  antenna's chains were all confirmed correct at every layer,
  including firmware-side gating logic and each bridge node's
  command-resend behavior. Microscope's wasn't.

  `app.js` had been correctly sending `driver_enable` in every
  microscope command since the button was built — the bug was
  entirely on the backend: `server.py`'s WebSocket dispatch for
  `"microscope"` never read it from the payload, and
  `ros_bridge.py`'s `send_microscope()` didn't even accept it as a
  parameter. The value was silently dropped before ever reaching the
  ROS message, which meant every microscope command carried
  `driver_enable=False` (a ROS bool field's own default) regardless
  of which button was clicked or what the button's label said.
  Clicking "enable" updated the button's own text and toggle state —
  which is why it could look like it was working — without ever
  actually being able to energize the driver, since the one value
  that mattered never left the browser. Confirmed the rest of the
  chain (bridge node, firmware) was already correct and just waiting
  for a real value to arrive - fixed at the two points responsible,
  not worked around further downstream.
- **Mast: automatic, thermostatically-controlled cooling fan** — a
  generic N-channel MOSFET driver module (IRF520-style: SIG/VCC/GND
  control header, V+/V- screw terminals for the load), entirely
  closed-loop against the mast's own DS18B20 reading, not
  operator-commanded — no field for it on `MastCommand`, only
  telemetry on `MastState` (`fan_duty_percent`, 0-100).

  **Wiring is a low-side switch, worth being explicit about since
  it's a common mix-up**: the fan's positive lead goes directly to
  the external supply (the module's V+/Vin, permanently on), and the
  MOSFET switches the fan's *negative* lead (through V-/OUT) to
  ground — not the fan's positive side the way a more intuitive
  high-side design might suggest. The module's VCC pin only powers
  its own onboard status LED and can be left disconnected; only GND
  and SIG are actually required for switching.

  **No hardware PWM pin was available for this** — the mast Uno's
  entire PWM budget (D3/D5/D6/D9/D10/D11) was already committed to
  the yaw/pitch/lift functions before this was added. `kFanPwmPin`
  (A2) runs a simple `millis()`-based software PWM instead
  (`updateFanPwm()`, 50Hz) rather than force a conflict — a MOSFET
  module switching a slowly-responding thermal load doesn't need
  hardware-timer precision the way a stepper pulse train does.

  **Thermostat thresholds are placeholders** (`kFanOnTempDeciC`=35°C,
  `kFanOffTempDeciC`=30°C, `kFanMaxTempDeciC`=50°C,
  `kFanMinDutyPercent`=30%) — bench-tune once the real enclosure's
  actual thermal behavior is known, the same as every other
  uncalibrated constant in this project. `kFanOffTempDeciC` sits
  below `kFanOnTempDeciC` deliberately (hysteresis): once running,
  the fan stays on until temperature drops to the *lower* threshold,
  not the one it turned on at, to avoid rapid on/off cycling right at
  a single boundary. Below `kFanOnTempDeciC` the fan is off; between
  the ON and MAX thresholds its duty cycle ramps linearly, clamped to
  at least `kFanMinDutyPercent` once running — many small DC fans
  won't reliably start or stay spinning much below that, so this
  avoids a smooth ramp landing right at a near-zero, potentially-
  stalling duty cycle.

  **A deliberate fail-safe choice, not an oversight**: if the DS18B20
  itself isn't responding (`cachedTemperatureDeciC` at its own
  `-9999` sentinel), the fan defaults to running at
  `kFanMinDutyPercent` rather than staying off. Unnecessary fan noise
  is a minor cost; an overheating board with no way to know it's
  overheating is a real one — the two failure modes aren't
  symmetric, so the default shouldn't be either.

  **Found and fixed while documenting this, not introduced by it**: all
  four protocol files, all four `.msg` files, and one `ros_bridge.py`
  state callback still described the temperature sensor as a BMP280
  over I2C — leftover language from before that sensor was replaced
  with the DS18B20 two sessions ago, missed at the time because the
  swap's own review focused on the firmware and the primary docs, not
  every inline field comment referencing it. Fixed all of it, not
  just the mast's own copy.

- **Temperature sensor on base, arm, mast, and antenna (not
  microscope) is a DS18B20, not a BMP280** — the BMP280/I2C version
  documented in an earlier session was fully replaced, not layered
  alongside; nothing about the temperature feature itself changed
  (same field, same wire format, same sentinel convention, same web
  GUI display), only the sensor hardware and the firmware talking to
  it.

  DS18B20, TO-92 package, communicates over 1-Wire on a single digital
  data pin rather than I2C's two-pin shared bus — no dedicated
  hardware pin requirement the way I2C's TWI peripheral has, so pin
  choice was open on all four boards. Reused each board's now-freed
  former I2C SDA pin rather than pick a new one (Mega: pin 20, Uno:
  A4) — avoids leaving a pin idle for no reason. **Requires an
  external 4.7kΩ pull-up resistor between DQ and VDD** — a real,
  physical component to add, not optional and not achievable via the
  Arduino's internal `INPUT_PULLUP` (documented as too weak to hold
  reliable 1-Wire bus timing).

  Libraries: **OneWire** (Paul Stoffregen, MIT) and **DallasTemperature**
  (Miles Burton, **LGPL-2.1**) — a third license in these firmware
  files alongside this project's own Apache-2.0. LGPL is generally more
  permissive than GPL-3.0 about linking against differently-licensed
  code, but that distinction matters less for a statically-linked,
  monolithic firmware binary than for a desktop application
  dynamically linking a shared library — worth its own explicit
  licensing review regardless, not waved off as equivalent to
  OneWire's own MIT license just because they're installed together.
  (This bullet used to also compare against ServoEasing's GPL-3.0 on
  the base board specifically - stale even before this session, since
  base's steering moved off ServoEasing several sessions ago, and the
  library is gone from this project entirely as of this session; see
  the dedicated servo-easing bullet elsewhere in this section.)

  **Read via a non-blocking two-phase state machine, not the
  library's own default blocking pattern.** The DS18B20's conversion
  takes up to ~750ms at full (12-bit) resolution — the library's own
  documented example simply calls `delay(750)` between requesting a
  conversion and reading it, which would stall `loop()` for 750ms on
  every read on boards whose actual job is real-time motor control.
  Instead: `requestTemperatures()` (non-blocking, via
  `setWaitForConversion(false)`) starts a conversion and returns
  immediately; a separate check on a later `loop()` iteration reads
  the result once the worst-case conversion time has elapsed,
  without ever blocking. Still on the same outer 1-second cadence as
  before (`kTemperatureReadIntervalMs`) for starting a new cycle — the
  underlying reason is unchanged: board temperature moves over
  seconds-to-minutes, not tens-of-milliseconds, so there's nothing to
  gain from polling faster than that regardless of how fast any given
  read technically could be.

  **A genuine improvement over the BMP280 version, not just a
  like-for-like swap**: DallasTemperature reports a specific
  `DEVICE_DISCONNECTED_C` sentinel on any read that fails, checked
  fresh on *every* cycle — unlike the BMP280 version's one-time
  `bmp.begin()` check at boot, a DS18B20 that's disconnected and later
  reconnected recovers on its own next read, with no reset needed.
  The wire-level sentinel this maps to (`-9999`, i.e. -999.9°C) is
  unchanged from before, still comfortably outside the DS18B20's real
  range (-55 to +125°C, wider than the BMP280's own -40 to +85°C, for
  what it's worth) — the web GUI's `formatTemperature()` needed no
  changes at all to keep rendering it as a plain "N/A".

- **Two real, pre-existing bugs found and fixed while building the
  antenna's web GUI/Xbox plumbing, not introduced by it** — both meant
  the mast's `driver_enable` field, added a couple of sessions back,
  never actually worked outside the one path that happened to get
  tested by hand:
  1. The web GUI's mast panel sent `driver_enable` in its WebSocket
     payload, but `server.py`'s dispatch never read it and
     `ros_bridge.py`'s `send_mast()` didn't even accept it as a
     parameter — the value was silently dropped before ever reaching
     the ROS message. `_on_mast_state()`'s telemetry capture had the
     same gap in reverse (never read `driver_enabled` back out of the
     state message), so the web GUI's `DRIVER: ENABLED/DISABLED`
     readout was always showing `DISABLED` regardless of the real
     state. Fixed in both directions.
  2. Separately, `xbox_teleop_node.py`'s `_handle_mast()` never set
     `cmd.driver_enable` at all, leaving it at its unset default
     (`False`, a ROS bool field's default). Since the firmware gates
     movement and enable/disable on the same command, this meant
     **Xbox controller mast control was completely non-functional**
     since `driver_enable` was introduced — every joystick command
     disabled the drivers at the exact moment it tried to move them.
     Fixed by setting `driver_enable = True` when actively jogging,
     matching how `_handle_arm` already sets `cmd.enable = True` for
     the same reason. Applied the same pattern to the antenna's own
     `_handle_antenna` from the start, rather than propagate the gap
     into new code.
- **A third instance of the same underlying bug class, this one only
  found by actually running the system, not caught in review** —
  `ros_bridge.py`'s `get_snapshot()` is a hand-constructed dict
  listing each subsystem's key explicitly, and "antenna" was simply
  missing from it, even though `self._state["antenna"]` was being
  correctly populated by `_on_antenna_state()` the whole time. The
  data existed server-side and never reached the frontend — every
  other piece (the telemetry panel's HTML, the JS rendering code, the
  ROS subscription) was correct in isolation, which is exactly why
  static review across several passes never caught it: nothing was
  individually wrong, one dict just never got the new key added to it.
  Fixed, and added a comment linking `get_snapshot()` to `self._state`'s
  own declaration explicitly, so the next subsystem addition has an
  actual pointer to keep these two in sync rather than relying on
  remembering to.
- **A fourth instance, same bug class again, this time affecting
  every subsystem's new `board_temperature_decic` field at once** —
  when that field was added (base, arm, mast, antenna), the ROS
  message, bridge nodes, and frontend rendering all got updated
  correctly, but `ros_bridge.py`'s four `_on_X_state()` callbacks —
  the code that actually unpacks an incoming ROS message into the
  dict `get_snapshot()` later serves — were never touched. The field
  existed on the wire and in the ROS message; it just never got
  copied out of it. Reported by the user as "antenna telemetry
  appears, but temp is missing" — checking confirmed it was missing
  from all four panels, not just the one that happened to get
  noticed first. Fixed all four, and extended the existing sync
  comment (see the bullet above) to name this specific class of
  callback as a third place that has to stay in sync, not just the
  two `get_snapshot()`/`self._state` already called out — this bug
  was in exactly the kind of spot that comment didn't yet cover.
- **A fifth instance, this one the actual explanation for what turned
  out to be two sessions of "the Antenna label is missing" reports**
  — `app.js`'s `BOARD_NAMES` array (four hardcoded `[board_name,
  display_label]` pairs, driving the left rail's board-status lamps)
  was never given a fifth entry for the antenna when that subsystem
  was built. Not a rendering bug, a CSS issue, or a stale cache, all
  of which got ruled out first, thoroughly, across the two prior
  reports — antenna's board-status lamp didn't render in the wrong
  state, it simply never existed, since the loop that builds each
  lamp row iterates this exact array and had no fifth board to
  iterate over. The backend side was already correct the whole time
  (`rover_antenna/board_status` was properly subscribed to and
  published), which is exactly why nothing on that side ever looked
  wrong under investigation — the gap was purely in this one frontend
  array. Confirmed the fix's key (`antenna_uno5`) matches exactly what
  `antenna_bridge_node.py` actually publishes before wiring it in,
  the same care this project has taken with board-name string matches
  since the mast's own Mega-to-Uno migration first surfaced this exact
  failure mode. Swept the rest of `app.js`/`ros_bridge.py`/`server.py`
  for any other hardcoded four-board list afterward rather than assume
  this was the only one — found none.
- **A sixth instance, in `index.html` itself, missed by that same
  sweep** — asked directly ("did you also forget index.html on the
  left rail?") after the fifth instance above, because that sweep
  only covered `app.js`/`ros_bridge.py`/`server.py` and, in hindsight,
  had no real reason to have covered the HTML too when the bug it was
  chasing was in a JS array. It should have swept wider. `index.html`
  has its own four static, hardcoded lamp rows for exactly the same
  left-rail list — a design detail worth understanding correctly:
  `app.js` clears and fully rebuilds this container
  (`lampList.innerHTML = ""`) on every telemetry update, so in normal
  operation with JS running these static rows are invisible, replaced
  before a user ever sees them. That does not make leaving them wrong
  acceptable — they're still incorrect markup, they're what actually
  renders if JS fails to load or errors out before this code runs, and
  the file should describe the real page regardless of whether
  something else immediately overwrites it. Fixed by adding the
  missing fifth row. Also found and fixed a second, unrelated,
  pre-existing staleness in the same four rows while there: the mast's
  said `MAST / MEGA #3`, unchanged since long before the antenna ever
  existed — the mast became an Uno many sessions ago, and `app.js`'s
  own `BOARD_NAMES` array had already been corrected to `MAST / UNO
  #3` at the time, just never mirrored back into this static
  duplicate. A concrete example of why keeping duplicated content in
  sync needs an explicit reason to trust it has been, not an
  assumption that it has.
- **Mast: "RETURN HOME" and "TRANSPORT POSITION" web GUI buttons** —
  both are ordinary `MastCommand`s (yaw/pitch only, `lift_mode`
  untouched), not new firmware or protocol capability: Return Home
  sends 0°/0°, Transport Position sends whatever's configured in
  `rover_mast/config/mast_topology.yaml`'s new
  `transport_head_yaw_deg`/`transport_head_pitch_deg` (placeholder
  0.0/0.0 — dead ahead, level — until a real safe transport
  orientation is known; tune those two values once it is, no code
  change needed either way). Deliberately doesn't also command the
  lift — sequencing "re-center the head, then stow" vs. "stow, then
  re-center" is left to the operator via the existing Stow button,
  rather than baked into one fixed order.
- **`max_head_yaw_deg`/`max_head_pitch_deg` deduplicated** — found
  while adding the above: this pair was declared independently in
  both `rover_mast/config/mast_topology.yaml` (unused there —
  `rover_mast_bridge` never actually read it) and
  `rover_teleop/config/xbox_teleop.yaml` (the one actually used, for
  MAST-mode stick-to-angle scaling), with no shared source of truth
  between the two copies. Consolidated into `mast_topology.yaml`'s own
  `/**:` shared block — the same fix `drive_sensitivity.yaml` already
  applied to `max_linear_mps`/`max_angular_radps`/`deadzone` — and
  `xbox_teleop.launch.py` updated to load it from there instead.
  `rover_web_gui` now loads this same file too, for the transport
  position values above.
- **Mast pitch range corrected: ±60° was wrong, real range is ±180°** —
  confirmed against real hardware while adding the post-calibration
  sequence below (needed a genuine target position, 170°/180°, that
  turned out to exceed the old placeholder). Updated everywhere that
  figure was used: `mast.xacro`'s joint limit, `mast_topology.yaml`'s
  `max_head_pitch_deg`, `joy_mapping.py`'s fallback default, the web
  GUI's pitch slider range, and — because pitch is now the *larger* of
  the two ranges (360° total vs. yaw's 340°) — the reasoning behind
  `mast_uno3.ino`'s `kHomingMaxTravelSteps` safety margin, which used
  to size itself specifically against yaw being the bigger one. The
  numeric margin (500°) still comfortably covers the new range without
  needing to change, but the comment explaining *why* did.
- **Mast: calibration now offsets to each axis's minimum, then drives
  to true zero from there — not "zero at the switch, then a separate
  verification move"** — corrected from an earlier version of this
  same feature (see `docs/journal.md` for that history) that had it
  backwards: each limit switch is physically at that axis's minimum
  bound (-170° yaw, -180° pitch — real, bench-confirmed values, not
  placeholders), not its center, so `serviceHoming()` now recognizes
  triggering it as reaching that minimum (`setCurrentPosition()` to
  the minimum in steps, not to 0), then drives from there to true
  zero. Only once both axes actually arrive does `homed` become true —
  this is genuinely what "home" means here, the centered position
  reached *from* the minimum, not the minimum itself — and the TB6600
  drivers disable themselves (`servicePostCalibration()`, now a single
  move-to-zero phase instead of the previous two-phase verify-then-zero).
  `MastCommand`'s `driver_enable` field and the web GUI's matching
  `CLOSE DRIVER (ENABLE)`/`OPEN DRIVER (DISABLE)` toggle are unchanged
  by this correction — both are still needed so the mast stays usable
  after the sequence auto-disables it.

  The gating logic this required is unchanged too, and the reasoning
  behind it matters enough to spell out regardless of which version of
  the sequence is running: `rover_mast_bridge` sends `MastCommand`
  frames continuously at its own control rate once past its one-shot
  homing request — using whatever's in its last-known command, which
  starts as all-zero/disabled before the operator has ever touched the
  mast panel. Applying `driver_enable` unconditionally on every frame
  (the way the arm's own enable field works) would disable the drivers
  mid-seek or mid-move-to-zero from nothing more than the bridge's own
  routine resend — indistinguishable at the protocol level from a
  genuine command — stranding a stepper that can't move de-energized.
  Both `driver_enable` and yaw/pitch targets are gated on a single
  check now (`if (homed)`), which is enough on its own: `homed` is
  already false for the entire seek-then-move-to-zero sequence, so
  there's no separate "is a sequence currently active" flag needed
  the way an earlier version of this required.
- **Base steering servos: per-corner calibration, not one shared set** —
  `base_mega1.ino`'s `kServoMinUs`/`kServoMaxUs`/`kServoNeutralUs`
  became 4-entry arrays (FL, FR, RL, RR), replacing one set of
  constants shared across all four. The file's own comment had always
  said to "bench-test each servo," but the code only ever supported
  tuning them all identically — real 40kg servos, even same model and
  batch, vary enough in actual center/travel that a shared calibration
  was only ever a starting point. Fixed a real accuracy bug in the
  same pass: the angle-to-pulse-width conversion always scaled off the
  max-side span (`kServoMaxUs - neutral`), even for negative angles,
  which is only correct if neutral happens to sit exactly centered
  between min and max. A real bench-calibrated servo often won't -
  using the wrong span for negative angles doesn't just misreport the
  angle, it silently shrinks the achievable range on whichever side is
  shorter. Now uses the min-side span (`neutral - kServoMinUs`) for
  negative angles and the max-side span for positive ones. All four
  corners still start at identical placeholder values (600/2400/1500us) -
  intentional, not an oversight, until each is actually bench-tested.
- **Servo movement: eased, not instant, on both axes that move a
  physical servo — and, as of this session, neither one via
  ServoEasing anymore.** The microscope's lens cover moved off
  ServoEasing too, at the user's own explicit request - unlike the
  base's steering servos below, this wasn't a technical necessity
  (ServoEasing genuinely can't drive a PCA9685; the cover servo is
  still direct-pin, so ServoEasing itself would have kept working
  fine here) but a deliberate choice. Smoothed movement was preserved
  anyway, reimplemented as the same kind of small, non-blocking
  custom ramp (`updateCoverEasing()` in `microscope_uno4.ino`,
  mirroring `base_mega1.ino`'s own `updateSteerEasing()` almost
  exactly) rather than dropped to an instant snap - this project has
  consistently valued eased servo motion, and removing one specific
  library was never a reason to lose it. `kCoverEaseSpeedDegPerSec` =
  60°/s (slower on purpose, since the cover is a rarely-triggered
  binary toggle rather than a continuously-recommanded value under
  responsiveness pressure) is unchanged in value and meaning, just
  read by a different mechanism now - still a placeholder like every
  other uncalibrated constant in this project, pending bench-tuning.

  **The base's 4 steering servos moved off ServoEasing entirely** when
  they moved to a PCA9685 (see the dedicated bullet on that below) -
  ServoEasing doesn't work with an I2C PWM driver, only direct-pin,
  standard-Servo-library-style control. Smoothed movement was
  reimplemented as a small, non-blocking custom ramp
  (`updateSteerEasing()` in `base_mega1.ino`) rather than dropped -
  every corner's commanded position moves toward its latest target at
  a fixed rate (`kSteerEaseSpeedUsPerSec`, 3000us/sec - a direct
  translation of the previous 300°/s ServoEasing rate into this
  board's own pulse-width terms, not a re-guess) each `loop()`
  iteration, rather than jumping there in one write. Both axes still
  share the same underlying fix from when steering first got its own
  per-corner calibration (previous bullet): a servo's actual physical
  position at power-on is unknown to either mechanism, so both seed
  their own tracking at each servo's calibrated neutral/closed
  position and write it immediately at boot, rather than let the
  first real command jump from an assumed, possibly-wrong starting
  point.

  **Licensing note, stated plainly rather than as a legal opinion**:
  ServoEasing is GPL-3.0, while the rest of this project's ROS
  packages are Apache-2.0 - this used to be worth flagging per-board
  (base's steering lost it several sessions ago; the microscope's
  cover kept it until this one). **As of this session, ServoEasing no
  longer appears anywhere in this project at all** - confirmed
  directly (`grep -rn "ServoEasing" firmware/`) rather than assumed
  from memory. A firmware binary
  that compiles in GPL-3.0 code is generally itself subject to
  GPL-3.0's copyleft terms if that binary (or the sketch producing it)
  is ever distributed to others - this concern is now retired for
  this project's firmware entirely, not just reduced on one board.

- **Microscope: cover open/close became two explicit buttons, not one
  toggle; LED gained on/off buttons alongside its existing slider.**
  Both requested together with the ServoEasing removal above. The
  cover's web GUI control changed from a single button that flipped
  its own label and state each click to two separate, stateless
  buttons (`OPEN COVER`/`CLOSE COVER`) - matching this project's own
  established pattern for a binary physical state (see the mast's own
  `ERECT`/`STOW` buttons for the precedent this follows) rather than
  inventing a new one. The actual current state is read from the
  telemetry panel's own `COVER` field, not tracked by which button was
  clicked last.

  **LED PWM interpretation, stated explicitly so it can be corrected
  if wrong**: requested as "change the PWM function to 0~5V for
  dimming" - standard Arduino PWM on a 5V board already swings between
  0V and 5V (duty-cycle-modulated, not a filtered analog level), which
  is exactly what this board's existing `analogWrite()`-based LED
  dimming already does. Read as describing that existing mechanism
  rather than requesting new filtering hardware (an RC low-pass
  filter or similar, to produce a true analog DC level rather than a
  switched signal) - no firmware or wiring change was made to the LED
  output itself, only the web GUI gained `LED ON`/`LED OFF` buttons
  alongside the existing brightness slider, setting it to 255 or 0
  respectively and keeping the slider's own displayed value in sync
  either way it's driven. Flag this back if an actual analog dimming
  circuit was intended instead - that would be a real hardware
  addition, not a firmware-only change.
- **Base steering: moved from direct Mega pins to a PCA9685, reversing
  an earlier explicit decision** — an earlier session's own header
  comment said plainly "no PCA9685 (middle wheels are fixed)"; this
  session added one back, deliberately. `base_mega1.ino`'s 4 steering
  servos now connect to a PCA9685 16-channel I2C PWM driver (channels
  0-3 -> FL/FR/RL/RR) instead of Mega pins A4-A7 directly.

  **CORRECTED: address is 0x40 (factory default, unjumpered), not
  0x70 as an earlier version of this same entry said** — a real
  mistake in that earlier session, caught by the user's own I2C scan
  turning up 0x70 on a board that hadn't been jumpered yet. 0x70 isn't
  a normal, jumper-configurable slave address on this chip at all -
  it's the PCA9685's built-in "LED All Call" address, enabled on
  every unit at power-up regardless of A0-A5 jumper state (stated
  directly in the chip's own datasheet: "the default LED All Call
  I2C-bus address... must not be used as a regular I2C-bus slave
  address since this address is enabled at power-up"; Adafruit's own
  FAQ says it more plainly still - "set it to 0x71 or anything other
  than the default 0x70"). This project only ever has one PCA9685, so
  there's no reason to move it off 0x40 at all - no jumpers to solder,
  `kPca9685Address` in firmware matches the factory-default address
  directly.

  **A real pin conflict had to be resolved, not just a new pin
  chosen**: I2C on a Mega is hardwired to pins 20 (SDA) and 21 (SCL) -
  not configurable the way 1-Wire is - and pin 20 was already
  committed to the DS18B20's own data line (moved there in an earlier
  session specifically because it was the Mega's *former*, then-unused
  SDA pin). Moved the DS18B20 to A4 instead - one of the pins the
  steering servos vacated moving to the PCA9685 - rather than search
  for a third free pin or leave a genuine conflict unresolved.

  **The PCA9685's V+ terminal restores a dedicated servo power rail**
  that the direct-pin version of this same steering setup never had
  and had to call out separately as a gap to fill: wire V+ to its own
  adequately-rated 5-6V supply (four 40kg-class digital servos can
  draw well beyond what the Mega's onboard 5V regulator safely
  delivers), sharing ground with the Arduino, never from the Mega's
  own 5V pin.

  Library: **Adafruit PWM Servo Driver Library** (BSD licensed,
  confirmed against the library's own source headers directly rather
  than trusted to a third-party index that shows "NOASSERTION" for it
  - a known quirk of automated license detection against a
  non-standard header format, not an actual absence of a license).
  `writeMicroseconds()` needed no rework of the existing per-corner
  `kServoMinUs`/`kServoMaxUs`/`kServoNeutralUs` calibration arrays at
  all - the library's own example code happens to use the identical
  600-2400us convention this project's placeholders already used, and
  the angle-to-microseconds math itself is entirely independent of
  which mechanism ultimately receives the resulting value.
- **Arm actuators: EBA-17-M planetary gearbox, 120:1, per joint** —
  updates the arm's originally-placeholder 5:1 gear assumption
  throughout: `steps_per_joint_rev` (200 full steps × 1/16
  microstepping × 120:1 = 384000, `rover_arm/config/arm_topology.yaml`
  and `trajectory_action_server.py`'s fallback default), the firmware's
  homing safety-cutoff (`arm_mega2.ino`'s `kHomingMaxTravelSteps`,
  scaled to preserve the same ~675° angular safety margin as before),
  and `arm.xacro`/`joint_limits.yaml`'s velocity/acceleration limits
  (recomputed from the firmware's own unchanged motor-shaft speed cap
  through the new, much higher reduction — not independently chosen).
  Worth being explicit about the real consequence, not just the
  numbers: achievable joint speed drops from what the old 5:1
  placeholder implied (~45°/s) to about **1.9°/s** at the same motor
  step rate — the genuine tradeoff of a 24× higher reduction ratio
  (more torque and precision, less speed). All five joints now show
  the *same* velocity/acceleration limit rather than the previous
  per-joint spread, correctly — that spread was never grounded in
  anything joint-specific, and all five share the same motor + gearbox
  + firmware speed cap. One more thing worth double-checking on the
  bench: the publicly documented ratio for the EBA-17/EBA-17-S product
  line (ToolBoxRobotics) is 38.4:1, not 120:1 — 120:1 is what was
  specified for the "M" variant actually in use here, but worth
  confirming against the datasheet/nameplate if these numbers ever
  look off in practice.

- **User-supplied URDF template**: a user-uploaded xacro file
  (differential/bogie suspension, "head" instead of the pan/tilt mast,
  `arm_j1`-`arm_j5` joint naming, solar panels, high-gain antenna,
  mesh-based visuals) was corrected — it had several real bugs
  independent of anything project-specific: empty wheel-generating
  macros producing no geometry at all, arm transmissions referencing
  joint names that didn't exist, a duplicate transmission name, an
  entire right-side suspension typed `fixed` with zero-width limits
  (permanently rigid) while the left side was fully functional,
  duplicate chassis links, missing mass/inertia, and 15 `<material>`
  references with no matching declaration anywhere. The corrected
  version is real and validated (`xacro` expansion plus a full link/
  joint/transmission consistency check both pass cleanly) but lives at
  `rover_description/reference/opportunity_style_template.urdf.xacro`,
  **not** wired into the active model — its wheel/arm architecture and
  naming conflict directly with `rover_base`'s kinematics and the
  MoveIt config built in an earlier session, both keyed to this
  project's actual, hardware-tested joint names and topology. Swapping
  it in live would have silently broken both. The two genuinely new,
  non-conflicting pieces from that template — solar panels and a
  high-gain antenna — **were** added to the active model
  (`rover_description/urdf/accessories.xacro`), as primitive geometry
  rather than the template's mesh references (no `.stl` files were
  supplied, and this project's whole model has always used primitives
  — see `rover_description/meshes/README.md`). Both are `fixed`
  joints, not `revolute`: neither has real actuation hardware or
  firmware anywhere in this project, so making them look plannable
  would overstate what's actually there. A full migration to the
  corrected template's own architecture — if that turns out to be
  what's actually wanted — is real, scoped, deferred work; see "Known
  gaps."

- **FZ0430 voltage sensors**: one per Arduino Mega (base, arm, mast -
  not the microscope Uno, which wasn't asked for one), on analog pin
  A0 on each board, reporting the main battery supply in millivolts.
  "FZ043" in the original request is treated as shorthand for the
  FZ0430, a common 5:1 resistive-divider breakout (0-25V range on a
  5V-logic board) - flag this if a different sensor was actually
  meant. Conversion math
  (`(raw / 1023.0) * 25000.0` → millivolts) assumes the standard
  5V AREF and the module's documented 5:1 divider ratio; if your
  specific board's divider resistors measure differently, that's a
  one-line change to each firmware's `readSupplyVoltageMv()`.
  Voltage-only, no current sensing - see "Known gaps" for what that
  would take.
- **IMU board**: SparkFun VR IMU Breakout - BNO086 (Qwiic). Its factory
  I2C address is 0x4B, but that's inert here — its PS0/PS1 jumpers
  must be strapped for **UART-RVC** mode (not I2C), since it's wired
  via its UART edge pins to a Waveshare "USB TO TTL (B)" (CH343G),
  which is a plain USB-to-UART bridge and can't carry I2C at all. If
  you ever rewire it for genuine I2C, this UART-RVC driver no longer
  applies and you'd need an address-aware I2C driver instead — and
  note SparkFun's own docs advise against 8-bit AVR (Uno/Mega) hosts
  for that chip over I2C; they recommend an ESP32 or SAMD51.
- **Base wheel/steer kinematics**: exact instant-center-of-rotation
  geometric steering, standard differential/skid throttle mixing
  rather than an exact zero-slip velocity model. See "Base drive
  modes" above and `rover_base/rover_base/kinematics.py`.
- **Mast erect/stow**: modeled as a single revolute "pivot" joint
  driven by the lift DC motor (0° = horizontal/transport, 90° =
  vertical/service), since the spec describes it as "laterally
  pivoting," not as a linear lift.
- **Mast: Arduino Uno (was a Mega), HW-039 lift driver, yaw/pitch
  calibration switches** — the mast's controller was originally a
  Mega with no head calibration switches (head zeroed to whatever
  orientation it powered up in) and an assumed-generic 2-direction-pin
  H-bridge for the lift motor (no specific driver part number had been
  given). All three changed together: it's an Uno now, which meant a
  full pin remap under a genuinely tight budget (11 of the Uno's 12
  usable digital pins committed, one spare) since none of the old
  Mega-only pins (22, 23, 30, 31) exist on an Uno at all; yaw and
  pitch each got their own calibration switch and now home on startup
  through a sequential state machine mirroring `rover_arm`'s exact
  pattern (`mast_uno3.ino`'s `startHoming()`/`serviceHoming()`), not a
  new design invented from scratch; and the lift now drives through an
  HW-039 (dual BTS7960B half-bridge) module, whose native RPWM/LPWM
  interface is genuinely different from both the base's DRI0002
  boards (single direction pin + PWM) and the *previous* generic
  H-bridge assumption (PWM + 2 direction pins) — simplified to a
  single shared enable pin (R_EN/L_EN tied together) specifically to
  fit the Uno's pin budget, with R_IS/L_IS (current sense) left
  unconnected since this application doesn't need them. The lift
  itself still doesn't home — it has no step-relative position to
  zero, just directly-read limit switches — so lift commands work
  immediately regardless of yaw/pitch homing state, same as before.
- **Mast yaw/pitch: TB6600 driver (was A4988)** — a follow-up to the
  Uno rebuild above, prompted by a real debugging session: the
  original A4988 wiring never had an explicit enable pin driven by
  firmware at all, relying on whatever that specific breakout's
  floating-EN default happened to be. TB6600's opto-isolated ENA input
  is less forgiving of being left floating, so `mast_uno3.ino` now
  drives it explicitly (`kHeadEnablePin`) — shared between both axes,
  since this commits the very last available Uno pin (13), leaving the
  board's digital pin budget fully spent (12 of 12). Wiring is assumed
  common-anode (PUL+/DIR+/ENA+ to +5V, the three "-" lines to the
  Arduino pins, ENA active-low) — the standard way to drive one of
  these from 5V logic, but flip the enable polarity in firmware if
  wired common-cathode instead. TB6600 sets microstepping via DIP
  switches on the driver rather than firmware, same idea as an A4988's
  MS1/MS2/MS3 pins but physical rather than software-controlled —
  `kStepsPerDegYaw`/`kStepsPerDegPitch` (already placeholder values,
  not yet bench-calibrated) need to match whatever those switches are
  actually set to. STEP/DIR pin assignments themselves didn't change —
  TB6600's PUL/DIR inputs are functionally identical to STEP/DIR from
  AccelStepper's perspective, so this was a wiring-and-firmware-enable
  change, not a pin-remap.
- **Arm: mixed drivers — J1-J3 TB6600, J4/J5 still A4988** — unlike
  the mast's two TB6600s, which share one enable pin, each of the
  arm's three TB6600 drivers gets its own independent enable pin
  (`arm_mega2.ino`'s `kTb6600EnablePin[3]`, pins 13/14/15). This is a
  real electrical distinction, not inconsistency for its own sake:
  TB6600's opto-isolated ENA input sinks real current per board
  (roughly 10-15mA, driver-dependent) when driven active, and ganging
  three of them onto one Arduino pin risks exceeding a single GPIO's
  safe sink rating (~20-40mA depending on the chip) — a risk the
  mast's two-board case didn't carry as heavily, and one the Mega's
  abundant spare pins (unlike the mast's tightly-budgeted Uno) meant
  there was no real reason to accept anyway. J4 and J5's A4988s keep
  sharing one enable pin between the two of them (`kA4988EnablePin`,
  still pin 12) — A4988's EN is a simple direct-logic input, not
  opto-isolated, and safely shareable the same way all five joints
  used to share this exact pin before the split. One real consequence
  worth flagging: `arm_topology.yaml`'s `steps_per_joint_rev` is still
  five identical values, but that's no longer guaranteed correct —
  TB6600 sets microstepping via DIP switches, and there's no guarantee
  those end up matched to the A4988s' own microstepping setting. If
  they don't, this needs five genuinely different values, not five
  copies of one; `joint_conversion.py` already handles that correctly
  per-joint (see its own tests), so it's a "measure and update the
  yaml" task, not a code change, whenever the real hardware is bench-verified.
- **Microscope focus/zoom**: modeled as a single combined stepper axis
  (as literally specified: "a stepper motor ... for focusing and
  zooming") rather than two independent axes. No calibration switch
  either — same power-on-zero convention the mast head used to use,
  before this session's calibration switches gave it a real one.
- **Microscope: DRV8825 replaces ULN2003, 24BYJ-48 replaces 28BYJ-48** —
  a real compatibility question, not just a part swap: DRV8825 is a
  bipolar-only driver, and both the 28BYJ-48 and 24BYJ-48 ship as
  5-wire unipolar motors. They're only usable together with a specific
  wiring technique — connect just the four coil-end wires to the
  driver's two coil outputs and leave the center-tap (common) wire
  completely disconnected, effectively treating the motor as a 4-wire
  bipolar one. This is a documented, real technique, not something
  improvised for this project, but it's an easy wire to connect by
  mistake, and doing so can short part of a coil — flagged prominently
  in `microscope_uno4.ino`'s header, worth reading before wiring this
  up. Also requires the 12V-rated 24BYJ-48 variant (DRV8825 needs
  8.2-45V on its motor supply; the 5V variant won't work). Upside: this
  unifies the microscope's stepper control with the arm and mast's own
  STEP/DIR/ENABLE pattern (`AccelStepper::DRIVER`), replacing ULN2003's
  4-pin phase sequencing — one less pin needed, and a driver with a
  real enable pin where the old one had none.
- **"Open/close driver" read as enable/disable** — DRV8825's new
  enable pin (`MicroscopeCommand.driver_enable`) is exposed as a web
  GUI toggle, labeled `CLOSE DRIVER (ENABLE)` / `OPEN DRIVER (DISABLE)`
  — mapped to the electrical open-circuit (no current, disabled) /
  closed-circuit (current flows, enabled) convention. Flagging this
  explicitly since the mapping isn't the first thing everyone reaches
  for; the parenthetical on each button label exists specifically so
  the actual effect is never ambiguous regardless of which
  interpretation someone starts from. Starts disabled at boot, same
  convention as the arm/mast boards.
- **Lens cover open/close** — already existed (`scope-cover` button,
  full firmware/protocol/GUI wiring) before this session; confirmed
  rather than rebuilt.
- **Focus/zoom presets are client-side only** — the 3 "record"/"go to"
  button pairs remember slider positions in the browser's own JS
  state, with no firmware, protocol, or backend involvement at all.
  Deliberately lightweight for what's fundamentally a convenience
  feature: presets don't survive a page reload, and there's no
  persistence across sessions. If that turns out to matter, the
  natural upgrade is moving preset storage server-side (`ros_bridge.py`)
  so it survives a browser refresh — not a firmware change either way,
  since presets are just remembered `focus_target_steps` values, not a
  new hardware capability.
- **Arm inverse kinematics**: now available via MoveIt2
  (`rover_arm_moveit_config` + `rover_arm`'s `trajectory_action_server`)
  — see "Arm motion planning" below. `ArmCommand` itself is still
  joint-space (motor steps) only; MoveIt plans in task space and the
  trajectory action server converts each planned waypoint before it
  ever reaches `rover_arm_bridge`, which has no idea MoveIt is
  involved at all.
- **LIDAR/GPS/joystick drivers**: reused from the ROS ecosystem
  (`rplidar_ros`/`sllidar_ros2`, `joy`) rather than reimplemented —
  install these separately, see below.

## Building

For a full walkthrough (fresh-machine ROS 2 install, rosdep gaps,
Arduino firmware flashing, udev rules, per-subsystem verification,
troubleshooting table) see **`docs/INSTALL.md`**. Condensed version:

```bash
cd ~/mars_rover_ws
rosdep install --from-paths src --ignore-src -r -y
```

A few rosdep keys are worth a heads-up (mirroring issues hit on this
project before):
- `python3-pynmea2` may not resolve via rosdep on all Ubuntu 22.04
  setups — if it fails, `pip3 install pynmea2` directly.
- `python3-fastapi` / `python3-uvicorn` likewise — if rosdep can't
  find them, `pip3 install fastapi uvicorn`.
- `rplidar_ros` is **not** in this workspace; clone it (or
  `sllidar_ros2`) into `src/` yourself before building, or pass
  `use_lidar:=false` to bringup if you don't have the hardware yet.
- Arduino firmware needs the **AccelStepper** library
  from the Arduino Library Manager (no longer **ServoEasing** as of
  this session - it was previously needed for base_mega1's steering
  and microscope_uno4's lens cover servo, both of which now use a
  small custom easing ramp instead; see README's "Explicit
  assumptions" for the history. The standard **Servo** library, which
  ships bundled with the AVR core, is still used directly by both -
  nothing separate to install for that part), plus `firmware/common/RoverProtocol` installed as a
  library (copy that folder into your
  `Arduino/libraries/` directory, or Sketch → Include Library → Add
  .ZIP Library on it).

```bash
colcon build --symlink-install
source install/setup.bash
```

## Running

```bash
# Everything: base/arm/mast bridges, microscope, sensors, LIDAR, Xbox teleop, web GUI
ros2 launch rover_bringup bringup.launch.py

# Bench-testing without a controller or the LIDAR installed yet:
ros2 launch rover_bringup bringup.launch.py use_teleop:=false use_lidar:=false

# Visualize the URDF alone (no hardware needed):
ros2 launch rover_description display.launch.py
```

Ground control console: open `http://<rover-host>:8080/` in a browser.
The microscope panel has an "open in new tab" link
(`http://<rover-host>:8080/microscope`) for a dedicated, full-page
microscope view with its own snapshot/recording controls, per the
project brief.

Xbox 360 controller: hold **RB** (deadman) for any command to leave
neutral, **LB** cycles DRIVE → ARM → MAST → MICROSCOPE. See
`rover_teleop/config/xbox_teleop.yaml` for the full mapping and a
reminder to verify axis/button indices against your actual
driver (`ros2 topic echo /joy`) before relying on it.

## Testing

Every serial protocol, the base kinematics, the BNO086 UART-RVC frame
parser (checksum verified against the datasheet's own worked example),
the GPS NMEA parser, the Xbox teleop mapping, and the udev device
identification/rules-generation logic all have unit tests that run
with plain `pytest` — no ROS 2 install, hardware, or colcon build
required:

```bash
cd ~/mars_rover_ws
PYTHONPATH=src/rover_protocol python3 -m pytest src/*/test tools/test -q
```

207 tests as of the last update. Before touching firmware or protocol
code again, also run the syntax/parse sweep:

```bash
python3 tools/validate_workspace.py
```

## Known gaps / natural next steps

- A corrected, validated, but **not active** alternative rover model
  (differential/bogie suspension, `arm_j1`-`arm_j5` naming) sits at
  `rover_description/reference/opportunity_style_template.urdf.xacro`.
  If that architecture is actually wanted over the current one, the
  real work is reconciling it with `rover_base`'s kinematics
  (currently built for 4-corner-steering + 2 fixed middle wheels, not
  a differential/bogie linkage), `rover_arm`'s joint names/limits
  (`arm_topology.yaml`, `joint_conversion.py`), the MoveIt SRDF, and
  every wiring diagram — a deliberate migration, not a file swap. See
  "Explicit assumptions" for what was and wasn't done with it.
- Voltage monitoring (base/arm/mast, FZ0430 sensors) is voltage-only —
  no current sensing, and no low-voltage warning in the web GUI. The
  latter was deliberately left out rather than guessed at: a sensible
  threshold depends on the actual battery chemistry/cell count, which
  isn't specified anywhere in this project yet. Cheap to add
  (`formatVoltage()` in `app.js`) once that's known.
- `udev` rules ship with placeholder VID:PID/serial values captured
  from no particular hardware — run `python3 tools/identify_rover_devices.py`
  (see docs/INSTALL.md Section 8) to generate a real, filled-in rules
  file interactively instead of hand-editing the placeholders.
- SLAM/Nav2 are wired up but ship with standard, untuned starting
  parameters (see "Navigation" above) — expect to adjust costmap
  inflation and controller behavior against your actual environment.
- MoveIt2's arm planning config (`rover_arm_moveit_config`) is
  hand-authored, not generated by MoveIt Setup Assistant, and several
  values are explicitly-flagged placeholders rather than measured from
  the real hardware — acceleration limits in `joint_limits.yaml`, and
  the collision matrix in the SRDF, which covers the arm's own chain
  but isn't an exhaustive whole-rover pass. See "Arm motion planning"
  below and the comments in those files for specifics.
- `rover_web_gui`'s ROS-facing code has no automated tests (it needs a
  live rclpy environment to exercise meaningfully); the pure protocol
  and kinematics logic it depends on is fully covered instead.

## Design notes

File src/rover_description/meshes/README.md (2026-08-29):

# Meshes

No mesh files ship with this workspace yet. The active model
(`rover.urdf.xacro` and everything it includes) uses simple box/
cylinder primitives throughout, matching this project's established
style, and doesn't need any mesh files to render.

`rover_description/reference/opportunity_style_template.urdf.xacro` -
a corrected, valid reference template adapted from a user-supplied
file, not currently wired into the active model - does reference mesh
files here (`package://rover_description/meshes/body_box.stl`,
`arm_j1.stl`, etc.) that don't exist. That file's own xacro expansion
and structural validity don't require the files to actually be
present (verified: `xacro` expansion and a full link/joint/transmission
consistency check both pass cleanly without them) - they'd only be
needed to actually see the model rendered in RViz or Gazebo.

If mesh-based visuals are wanted later, drop the corresponding `.stl`
files here with names matching the `<xacro:property>` declarations at
the top of that reference file, and it should render as-is.

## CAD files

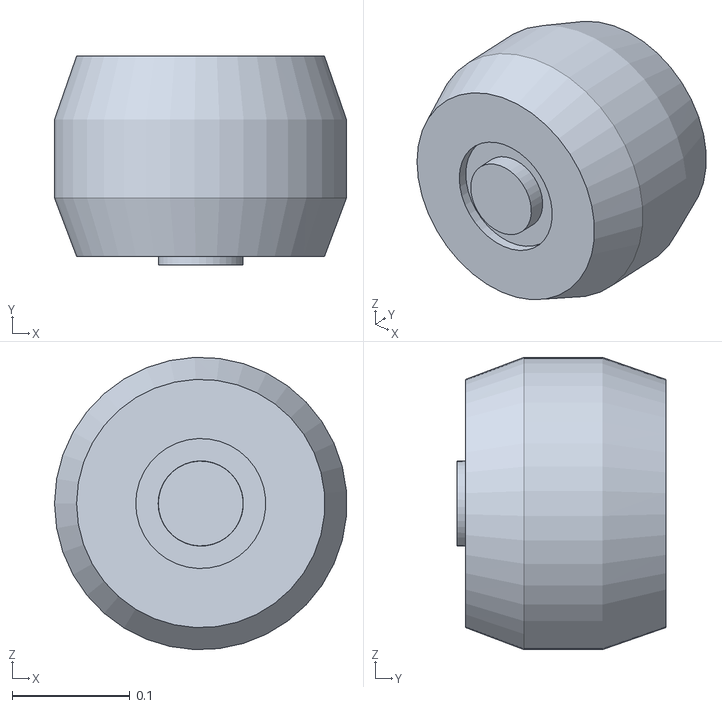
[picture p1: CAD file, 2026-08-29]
src/rover_description/meshes/middle_right_wheel.stl
0.248 x 0.177 x 0.248

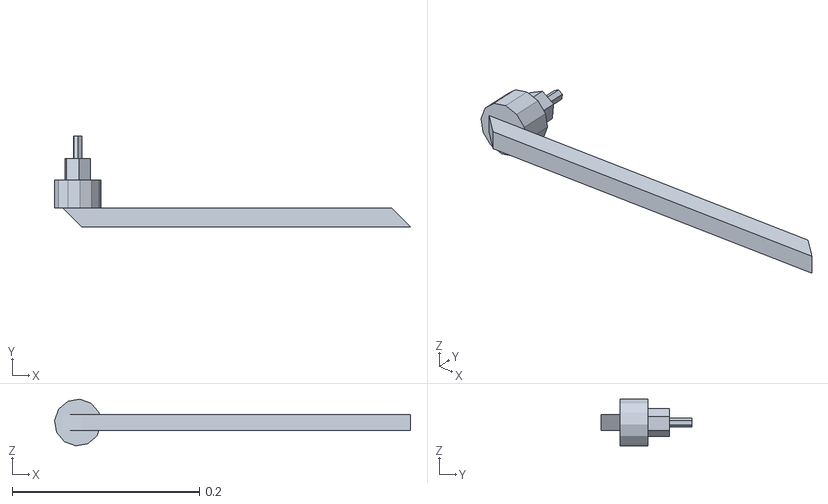
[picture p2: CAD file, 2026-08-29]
src/rover_description/meshes/arm_j3.stl
0.38 x 0.097 x 0.0498

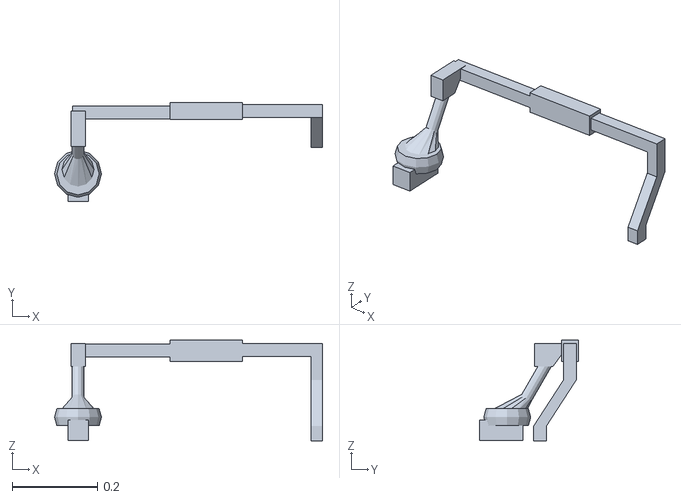
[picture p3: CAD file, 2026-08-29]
src/rover_description/meshes/right_bogie.stl
0.627 x 0.232 x 0.236

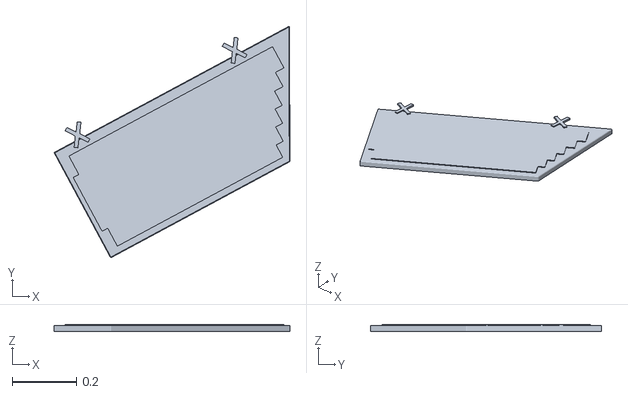
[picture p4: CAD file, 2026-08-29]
src/rover_description/meshes/front_right_panel.stl
0.735 x 0.72 x 0.023

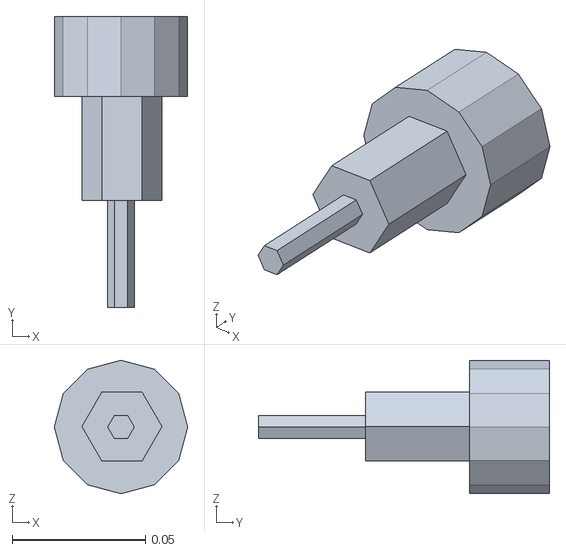
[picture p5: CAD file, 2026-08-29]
src/rover_description/meshes/arm_j4.stl
0.05 x 0.109 x 0.05

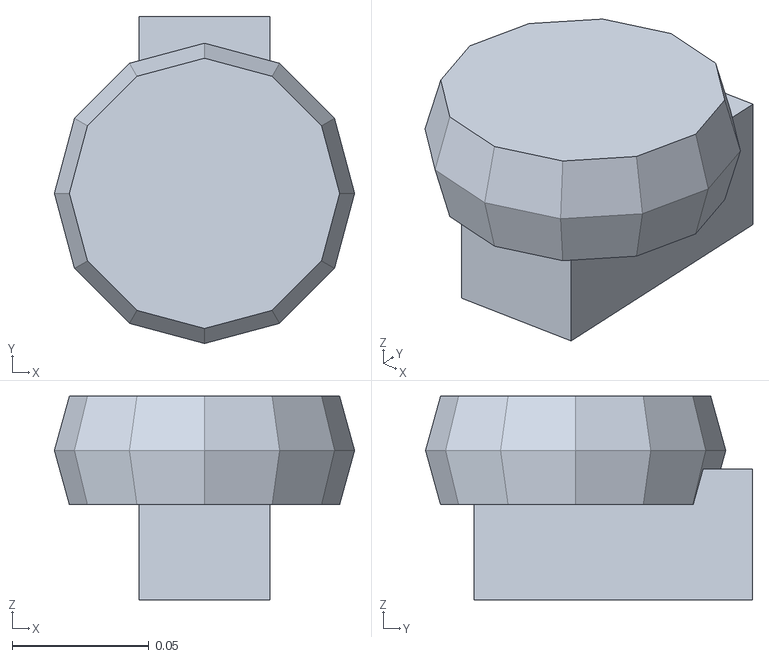
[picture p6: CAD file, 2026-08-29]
src/rover_description/meshes/rear_left_steering.stl
0.11 x 0.12 x 0.0746

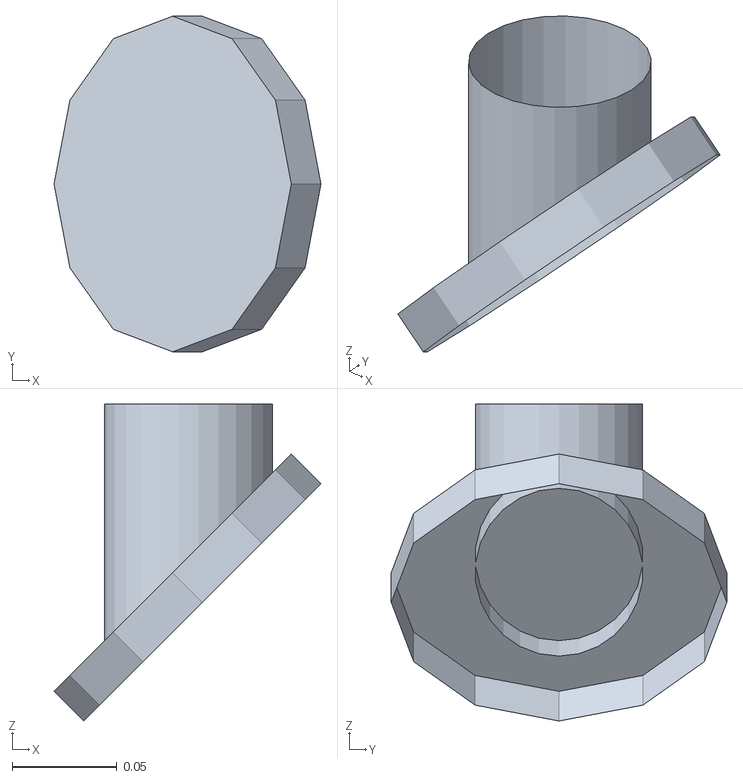
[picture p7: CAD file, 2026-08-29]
src/rover_description/meshes/head_tuck.stl
0.127 x 0.16 x 0.151

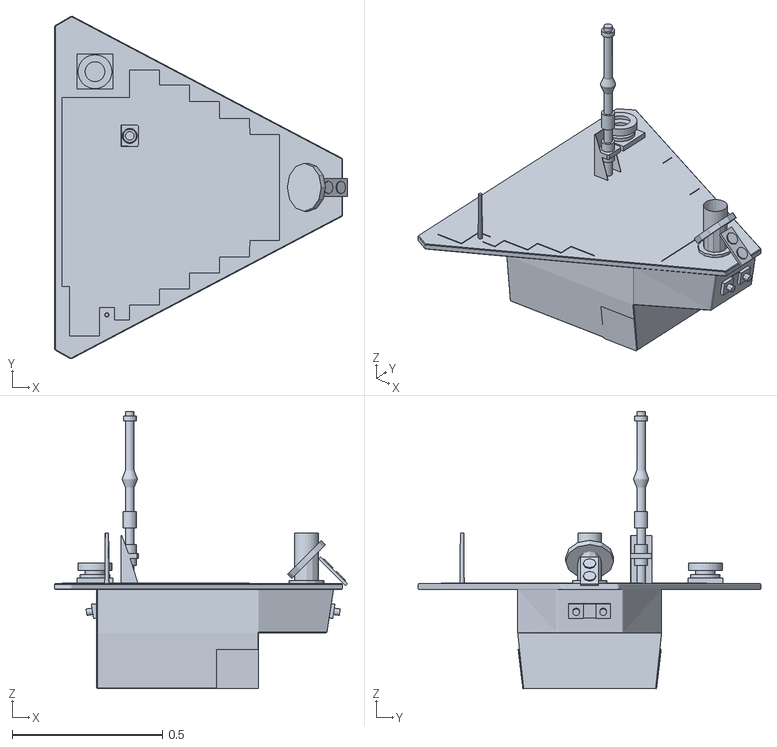
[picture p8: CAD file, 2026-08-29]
src/rover_description/meshes/body_box.stl
0.976 x 1.14 x 0.924

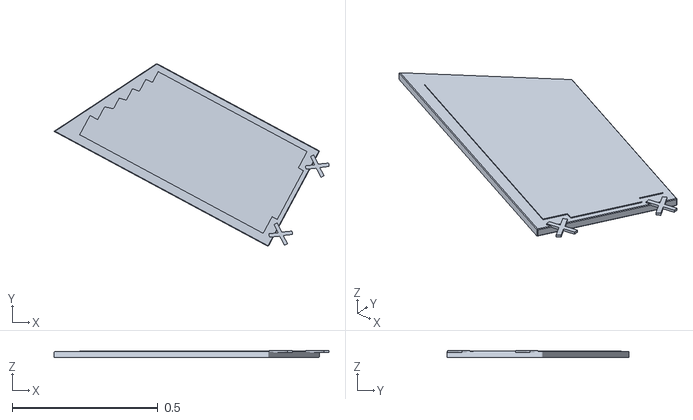
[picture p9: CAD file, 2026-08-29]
src/rover_description/meshes/rear_left_panel.stl
0.944 x 0.627 x 0.023

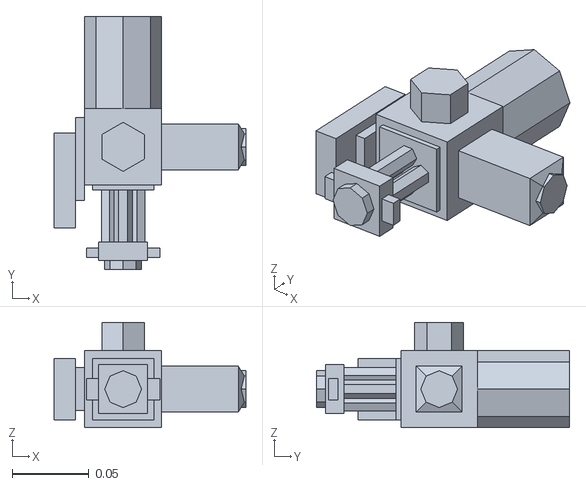
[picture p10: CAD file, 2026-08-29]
src/rover_description/meshes/arm_j5.stl
0.125 x 0.165 x 0.0684

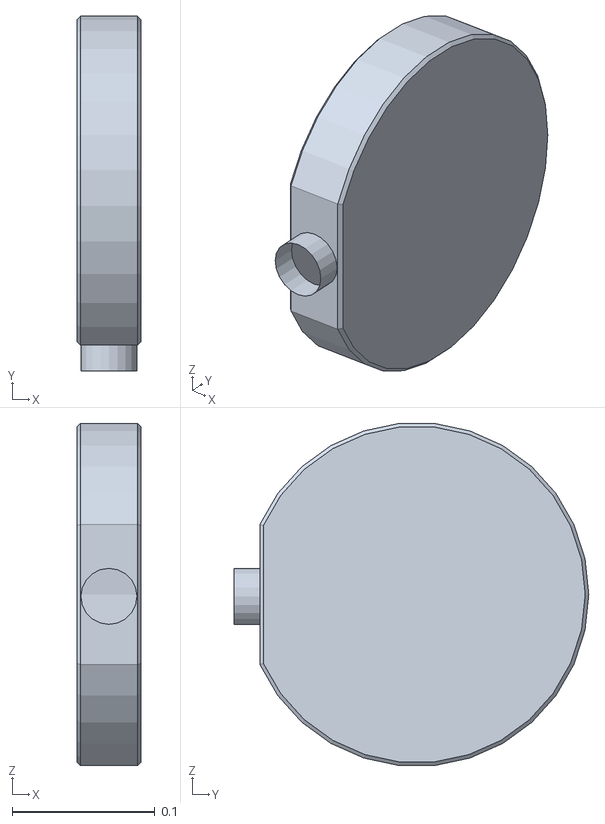
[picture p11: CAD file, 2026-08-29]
src/rover_description/meshes/ant_j2.stl
0.0451 x 0.248 x 0.239

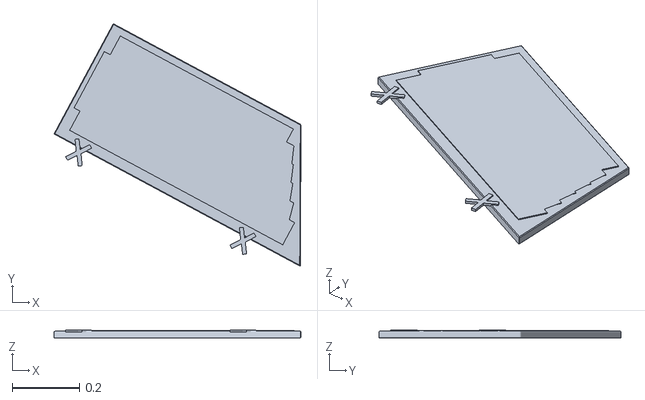
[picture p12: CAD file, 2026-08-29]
src/rover_description/meshes/front_left_panel.stl
0.735 x 0.72 x 0.023

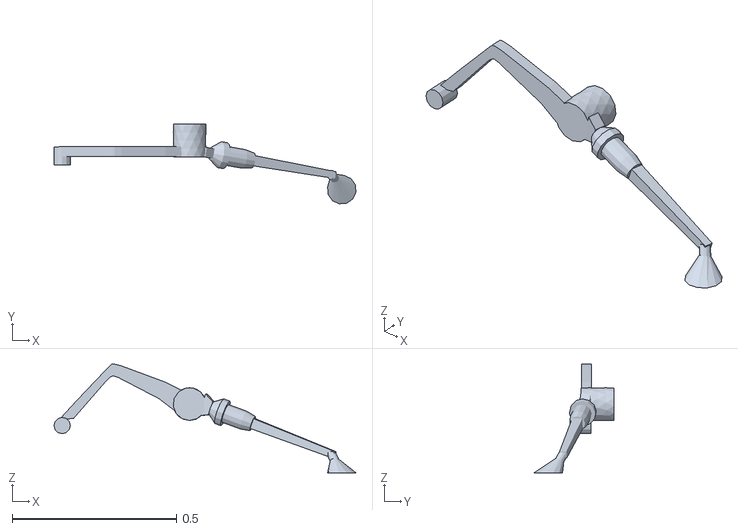
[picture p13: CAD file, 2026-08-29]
src/rover_description/meshes/right_differential.stl
0.921 x 0.243 x 0.331

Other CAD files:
src/rover_description/meshes/middle_left_wheel.stl
src/rover_description/meshes/front_left_wheel.stl
src/rover_description/meshes/left_bogie.stl
src/rover_description/meshes/rear_right_steering.stl
src/rover_description/meshes/ant_j1.stl
src/rover_description/meshes/arm_j1.stl
src/rover_description/meshes/arm_j2.stl
src/rover_description/meshes/front_left_steering.stl
src/rover_description/meshes/front_right_steering.stl
src/rover_description/meshes/front_right_wheel.stl
src/rover_description/meshes/head_j2.stl
src/rover_description/meshes/head_j3.stl
src/rover_description/meshes/left_differential.stl
src/rover_description/meshes/rear_left_wheel.stl
src/rover_description/meshes/rear_middle_panel.stl
src/rover_description/meshes/rear_right_panel.stl
src/rover_description/meshes/rear_right_wheel.stl

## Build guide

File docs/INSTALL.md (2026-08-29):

# Installation & Configuration Guide

Step-by-step setup for the rover workspace, from a bare Ubuntu 22.04.5
install through a full `ros2 launch rover_bringup bringup.launch.py`.
Written as a checklist — work through it in order the first time;
after that, jump to whichever section you need.

Companion docs: `README.md` (architecture/reference), `docs/journal.md`
(build history and decisions).

---

## Quick reference

For anyone who's done this before and just needs the commands:

```bash
# ROS 2 + build tooling
sudo apt install ros-humble-desktop python3-colcon-common-extensions python3-rosdep
sudo rosdep init && rosdep update
echo "source /opt/ros/humble/setup.bash" >> ~/.bashrc && source ~/.bashrc

# Workspace
cd ~ && unzip mars_rover_ws.zip && cd mars_rover_ws
rosdep install --from-paths src --ignore-src -r -y
pip3 install --break-system-packages pynmea2 fastapi uvicorn   # if rosdep can't resolve these
sudo usermod -aG dialout,video $USER   # then log out/in
colcon build --symlink-install
source install/setup.bash

# Test suite (no hardware/ROS needed)
PYTHONPATH=src/rover_protocol python3 -m pytest src/*/test tools/test -q

# Sensor fusion (always needed - runs as part of every normal bringup)
sudo apt install ros-humble-robot-localization ros-humble-geographic-msgs

# Optional: SLAM/Nav2 (only if you'll use use_slam:=true / use_navigation:=true)
sudo apt install ros-humble-slam-toolbox ros-humble-navigation2 ros-humble-nav2-bringup

# Optional: MoveIt2 arm planning (only if you'll use use_moveit:=true)
sudo apt install ros-humble-moveit ros-humble-moveit-configs-utils

# Bringup
ros2 launch rover_bringup bringup.launch.py
```

Everything below explains each of these, plus firmware flashing, udev
rules, and per-subsystem verification, which don't compress into a
snippet.

---

## 1. Host prerequisites

**1.1 Confirm the OS**

```bash
lsb_release -a
```
Expect `Ubuntu 22.04.5 LTS` (or close — any 22.04 point release is fine).

**1.2 Install ROS 2 Humble**, if it isn't already:

```bash
locale  # confirm UTF-8; if not, follow ROS 2's locale setup first
sudo apt install software-properties-common
sudo add-apt-repository universe
sudo apt update && sudo apt install curl -y
sudo curl -sSL https://raw.githubusercontent.com/ros/rosdistro/master/ros.key -o /usr/share/keyrings/ros-archive-keyring.gpg
echo "deb [arch=$(dpkg --print-architecture) signed-by=/usr/share/keyrings/ros-archive-keyring.gpg] http://packages.ros.org/ros2/ubuntu $(. /etc/os-release && echo $UBUNTU_CODENAME) main" | sudo tee /etc/apt/sources.list.d/ros2.list > /dev/null
sudo apt update
sudo apt install ros-humble-desktop python3-colcon-common-extensions python3-rosdep
```

**1.3 Initialize rosdep and source ROS** (every new shell needs this —
the last line makes it automatic):

```bash
sudo rosdep init   # "already exists" is fine if you've done this before
rosdep update
echo "source /opt/ros/humble/setup.bash" >> ~/.bashrc
source ~/.bashrc
```

**Verify:**
```bash
printenv ROS_DISTRO   # expect: humble
ros2 pkg list | head  # should print a long list without errors
```

If you skip 1.3, every `colcon build` fails with `Could not find a
package configuration file provided by "ament_cmake"` — that's the
single most common first-time mistake with this workspace.

---

## 2. Get the workspace

```bash
cd ~
unzip mars_rover_ws.zip     # produces ~/mars_rover_ws
cd ~/mars_rover_ws
ls src                       # should list all 15 rover_* packages
```

### Replacing an existing workspace with a newly-delivered zip

Not a fresh install — this is for when you already have a
`~/mars_rover_ws` from an earlier session and a new zip supersedes it
entirely. **Fully delete the old directory before extracting the new
one — don't extract on top of it.** Package contents get renamed,
merged, and removed between sessions (an old board's own directory
getting renamed is a real, recent example — `power_nano6/` became
`power_uno6/` in one past session), and extracting a new zip over an
old, un-deleted directory leaves both the new files *and* every
now-orphaned old one sitting side by side. That's not a cosmetic
problem — a stale, no-longer-referenced package or interface
definition left alongside its replacement is exactly the kind of thing
that produces confusing, hard-to-attribute build or runtime behavior
later, with no obvious cause in the current source tree to point at.

```bash
# 1. Stop everything currently running first (Ctrl+C any active
#    ros2 launch/ros2 run processes) - not strictly required to delete
#    files out from under a running process on Linux, but avoids any
#    confusion about which version of anything is actually active
#    while you're doing this.

# 2. Fully remove the old workspace - not an overlay, a replacement.
#    Back it up first only if you have local, uncommitted changes of
#    your own inside it worth keeping (this project's own iteration
#    doesn't preserve anything you edited by hand outside of what
#    was actually asked for).
rm -rf ~/mars_rover_ws

# 3. Extract the new zip fresh, same as a first-time install.
cd ~
unzip mars_rover_ws.zip
cd ~/mars_rover_ws

# 4. Full clean rebuild - not an incremental one. build/, install/,
#    and log/ are generated FROM src/, not part of the zip itself; a
#    partial or incremental build against a fully-replaced src/ tree
#    risks mixing artifacts compiled from the old source with the new
#    one. This is the same command this doc's own troubleshooting
#    table already gives for stale build dirs (below) - applied here
#    proactively, not just as a reaction to a specific error.
rm -rf build install log
colcon build --symlink-install

# 5. Re-source in every terminal that needs this workspace - a
#    terminal that sourced the OLD install/setup.bash before step 2
#    still has stale environment variables pointing at paths that no
#    longer exist; re-sourcing (or just opening a fresh terminal)
#    after the rebuild is what actually picks up the new one.
source install/setup.bash
```

If `rosdep`/`pip3` dependencies changed between the old and new zip
(a new package added, e.g.), re-run 3.1/3.2 below too before the
build step - a clean `src/` tree doesn't retroactively install
anything this workspace's own packages now depend on that wasn't
needed before.

---

## 3. Install dependencies

**3.1 rosdep** (pulls in rclpy, sensor_msgs, joy, pyserial, OpenCV
bindings, etc. from the package.xml files):

```bash
cd ~/mars_rover_ws
rosdep install --from-paths src --ignore-src -r -y
```

**3.2 Known rosdep gaps** — a few Python deps aren't reliably in every
Ubuntu 22.04 rosdep database. If `rosdep install` reports it can't
resolve any of these, install them directly:

```bash
pip3 install --break-system-packages pynmea2 fastapi uvicorn
```

(`--break-system-packages` is needed on Ubuntu 22.04's system Python;
omit it if you're inside a virtualenv instead.)

**3.3 External ROS packages not vendored in this workspace** — clone
these into `src/` before building:

```bash
cd ~/mars_rover_ws/src

# RPLIDAR C1 driver (pick ONE; rover_bringup's launch file expects
# rplidar_ros by default — see step 3.4 if you use sllidar_ros2 instead)
git clone -b ros2 https://github.com/Slamtec/rplidar_ros.git

# Xbox 360 controller raw input
sudo apt install ros-humble-joy

cd ~/mars_rover_ws
rosdep install --from-paths src --ignore-src -r -y   # re-run for the new package
```

**3.3b Sensor fusion packages** — needed unconditionally; sensor
fusion (wheel odometry + IMU, plus GPS conversion services) runs as
part of every normal bringup, not just when using SLAM/Nav2:
```bash
sudo apt install ros-humble-robot-localization ros-humble-geographic-msgs
```

**3.3c SLAM/Nav2 packages** — only needed if you actually plan to use
`use_slam:=true` or `use_navigation:=true` (see README's "Navigation"
section); skip this if you just want teleop/manual driving for now.
Unlike RPLIDAR/joy above, these install cleanly via `apt` — no need to
clone anything:
```bash
sudo apt install ros-humble-slam-toolbox ros-humble-navigation2 ros-humble-nav2-bringup
```

**3.3d MoveIt2 packages** — only needed if you plan to use
`use_moveit:=true` (see README's "Arm motion planning" section):
```bash
sudo apt install ros-humble-moveit ros-humble-moveit-configs-utils
```

**3.4 If you use `sllidar_ros2` instead of `rplidar_ros`:** open
`src/rover_bringup/launch/bringup.launch.py` and swap the package name
`rplidar_ros` → `sllidar_ros2` and the launch filename
`rplidar_c1_launch.py` → `sllidar_c1_launch.py` in the LIDAR
`IncludeLaunchDescription` block near the bottom of the file, and the
matching `<exec_depend>` in `src/rover_bringup/package.xml`.

**3.5 User permissions** — your user needs to be in `dialout` (serial
port access for the six Arduino boards) and `video` (USB cameras)
groups, or every serial/camera open will fail with a permissions error:

```bash
sudo usermod -aG dialout,video $USER
```
**Log out and back in** (group membership doesn't apply to your
current session otherwise) before continuing.

---

## 4. Build

```bash
cd ~/mars_rover_ws
colcon build --symlink-install
source install/setup.bash
echo "source ~/mars_rover_ws/install/setup.bash" >> ~/.bashrc
```

**Verify:**
```bash
ros2 pkg list | grep rover   # should list all 11 rover_* packages
```

### Troubleshooting the build

| Symptom | Cause | Fix |
|---|---|---|
| `Could not find a package configuration file provided by "ament_cmake"` | ROS 2 not sourced in this shell | `source /opt/ros/humble/setup.bash`, then rebuild |
| `package 'rover_X' found ... but libexec directory ... does not exist` | Stale `build`/`install` dirs from an earlier failed build | `rm -rf build install log && colcon build --symlink-install` |
| `rosidl_generate_interfaces` errors in `rover_msgs` | `std_msgs`/`builtin_interfaces` not resolved | `rosdep install --from-paths src --ignore-src -r -y`, rebuild |
| `ModuleNotFoundError: pynmea2` / `fastapi` / `uvicorn` at runtime | Step 3.2 skipped | `pip3 install --break-system-packages pynmea2 fastapi uvicorn` |
| `PermissionError` opening `/dev/ttyACM*` or `/dev/video*` | Not in `dialout`/`video` group, or didn't re-login | Step 3.5, then log out/in |
| `Package 'rover_X' not found: searching: ['/opt/ros/humble']` | Workspace `install/` never sourced in this shell (search list only has one entry), or that package never actually built | `ls install/ \| grep rover_X` to check it built; `source install/setup.bash` and confirm with `echo $AMENT_PREFIX_PATH` (expect two colon-separated paths, not one) |

---

## 5. Run the test suite (no hardware needed)

Do this now, before touching any hardware — it validates the serial
protocol, kinematics, and sensor parsers in isolation:

```bash
cd ~/mars_rover_ws
PYTHONPATH=src/rover_protocol python3 -m pytest src/*/test tools/test -q
```
Expect `207 passed`. If anything fails here, hardware bring-up isn't
going to work either — fix this first.

---

## 6. Arduino firmware

**6.1 Install the Arduino IDE** (2.x recommended):
```bash
sudo snap install arduino
```
or download from arduino.cc. `arduino-cli` works too if you prefer
the command line; the steps below assume the IDE's GUI.

**6.2 Add board support**: Tools → Board → Boards Manager → search
"Arduino AVR Boards" → Install (covers both the Mega 2560 and Uno).

**6.3 Install required libraries**: Tools → Manage Libraries, install:
  - **AccelStepper** (by Mike McCauley) — used by `arm_mega2`,
    `mast_uno3`, `microscope_uno4`, `antenna_uno5`
  - **Adafruit PWM Servo Driver Library** (by Adafruit) — used by
    `base_mega1` for the PCA9685 driving its 4 steering servos over
    I2C. BSD licensed (confirmed against the library's own source
    headers — some third-party library indexes show "NOASSERTION" for
    it, a known quirk of automated license detection against a
    non-standard header format, not an actual absence of a license).
  - **Servo** (bundled with AVR board support, nothing separate to
    install) — used directly by `microscope_uno4` (lens cover) for
    smoothed movement instead of an instant jump to each new
    commanded position, via a small non-blocking custom ramp
    (`updateCoverEasing()`) rather than the ServoEasing library this
    used before. **ServoEasing is no longer required by any board in
    this project** — `base_mega1`'s steering moved off it several
    sessions ago (its PCA9685 doesn't support it — it's built for
    direct-pin, standard-Servo-library-style control, not an I2C PWM
    chip), and `microscope_uno4`'s cover moved off it too, at the
    user's own explicit request (not a technical necessity this time
    — ServoEasing would have kept working fine on a direct-pin servo
    like this one). Both boards reimplement the same smoothed-
    movement idea themselves instead (`base_mega1.ino`'s
    `updateSteerEasing()`, `microscope_uno4.ino`'s
    `updateCoverEasing()`) — a genuine, project-wide side effect
    worth noting: this project no longer has a GPL-3.0 dependency
    anywhere (ServoEasing was the only one; see README's "Explicit
    assumptions" for the fuller history).
  - **OneWire** (by Paul Stoffregen) and **DallasTemperature** (by
    Miles Burton) — used by `base_mega1`, `arm_mega2`, `mast_uno3`,
    `antenna_uno5`, `microscope_uno4`, and `power_uno6` (all six
    boards) for each board's own temperature sensor (a DS18B20).
    Install both from the
    Library Manager. **Different licenses**: OneWire is MIT,
    DallasTemperature is **LGPL-2.1** — see `base_mega1.ino`'s own
    header comment for the licensing consideration, not a detail to
    wave off just because the two temperature libraries are installed
    together.
    **Requires an external 4.7kΩ
    pull-up resistor** between the DS18B20's DQ (data) pin and VDD —
    a real component to physically add, not optional, and not
    achievable via the Arduino's internal pull-ups (too weak for
    reliable 1-Wire timing). See 6.8 below for wiring.
  - **INA226** (by Rob Tillaart) — used by `power_uno6` for its two
    battery voltage+current monitors. MIT licensed. **No separate
    library needed for the TCA9548A multiplexer these sit behind** —
    channel selection is a single I2C write of one byte, not worth a
    dependency for. See 6.8d below for the mux/address reasoning and
    a real, must-verify shunt-resistor caveat before trusting current
    readings.

**6.4 Install the shared RoverProtocol library** (all six sketches
depend on this):
```
Sketch → Include Library → Add .ZIP Library...
```
Zip up `firmware/common/RoverProtocol/` first, or simpler: just copy
the folder directly —
```bash
cp -r ~/mars_rover_ws/firmware/common/RoverProtocol ~/Arduino/libraries/
```
Restart the IDE afterward so it picks up the new library.

**6.5 Flash each board — one at a time, with only that board plugged
in** (avoids ambiguity about which `/dev/ttyACM*` is which until udev
rules are in place in step 8):

| # | Sketch | Board type | Notes |
|---|---|---|---|
| 1 | `firmware/base_mega1/base_mega1.ino` | Arduino Mega 2560 | |
| 2 | `firmware/arm_mega2/arm_mega2.ino` | Arduino Mega 2560 | Mixed drivers - J1-J3 TB6600 (independent enable pins each), J4/J5 A4988 (shared enable pin) - see the file's own header comment |
| 3 | `firmware/mast_uno3/mast_uno3.ino` | Arduino Uno | Tight pin budget - all 12 usable digital pins committed (D2-D13, none spare), see the file's own header comment |
| 4 | `firmware/microscope_uno4/microscope_uno4.ino` | Arduino Uno | |
| 5 | `firmware/antenna_uno5/antenna_uno5.ino` | Arduino Uno | Same EBA-17-M + TB6600 combination as the arm's joints - see the file's own header comment |

For each: open the `.ino`, Tools → Board → select the correct type,
Tools → Port → select the port that appeared when you plugged it in,
click Upload. Watch for "Done uploading" with no errors.

**6.6 Bench-test each board before wiring it into the full rover** —
open the IDE's Serial Monitor at **115200 baud**, line ending "Newline",
and send raw protocol frames by hand to confirm the board responds.
For example, to the base Mega (all-zero drive command, checksum
precomputed):
```
D,0,0,0,0,0,0,0,0,0,0*44
```
You should see an `E,...` encoder frame come back. If nothing comes
back, double check baud rate, wiring, and that the correct sketch was
flashed to that board.

**Wheels off the ground (or at least the rover on blocks) before any
of this** — a wheel spinning at speed on a bench can walk the whole
rover off the edge. For the base Mega specifically, this is also the
right way to isolate *which* motor or servo has a wiring problem
before anything is wired to the whole vehicle: every checksum below
was computed by the real `rover_protocol.framing.encode_frame`, not by
hand, so a failure here means the hardware, not a typo'd frame.

```
All stop / centered                     D,0,0,0,0,0,0,0,0,0,0*44
FL wheel forward 30%                    D,300,0,0,0,0,0,0,0,0,0*47
FL wheel reverse 30%                    D,-300,0,0,0,0,0,0,0,0,0*6A
FR wheel forward 30%                    D,0,300,0,0,0,0,0,0,0,0*47
ML wheel forward 30%                    D,0,0,300,0,0,0,0,0,0,0*47
MR wheel forward 30%                    D,0,0,0,300,0,0,0,0,0,0*47
RL wheel forward 30%                    D,0,0,0,0,300,0,0,0,0,0*47
RR wheel forward 30%                    D,0,0,0,0,0,300,0,0,0,0*47
All six wheels forward 30%              D,300,300,300,300,300,300,0,0,0,0*44
FL servo to +30 deg                     D,0,0,0,0,0,0,300,0,0,0*47
FR servo to +30 deg                     D,0,0,0,0,0,0,0,300,0,0*47
RL servo to +30 deg                     D,0,0,0,0,0,0,0,0,300,0*47
RR servo to +30 deg                     D,0,0,0,0,0,0,0,0,0,300*47
All 4 servos to +60 deg (max)           D,0,0,0,0,0,0,600,600,600,600*44
All 4 servos to -60 deg (max)           D,0,0,0,0,0,0,-600,-600,-600,-600*44
```

Send **all-stop** between every test — don't rely on the 500ms
watchdog timeout during active testing. Field order in every frame is
`w_fl,w_fr,w_ml,w_mr,w_rl,w_rr,s_fl,s_fr,s_rl,s_rr` (see
`rover_base/rover_base/base_protocol.py`).

If a wheel spins the wrong way, fix `setWheelThrottle()` in
`base_mega1.ino` (flip the `HIGH`/`LOW`) - **don't** rewire the screw
terminal, that just moves the ambiguity around rather than resolving
it. If a servo moves the wrong direction, or hits a mechanical stop
before reaching the commanded angle, adjust that corner's own entry in
`kServoMinUs[]` / `kServoMaxUs[]` / `kServoNeutralUs[]` in the firmware
(indexed FL, FR, RL, RR, same order as `kSteerServoPin`) and/or
`max_steer_deg` in `base_topology.yaml` rather than force it. All four
corners start at identical placeholder values - that's intentional,
not a bug, since real servos vary enough that a shared calibration is
only ever a starting point; bench-test and tune each corner's own
three values independently as you go, without needing to touch the
other three corners' entries.

**6.7 FZ0430 voltage sensors** — base, arm, mast, and antenna (not
the microscope Uno) all have at least one battery-voltage reading;
**base specifically has two**, not one - see the note at the end of
this section for why. Each FZ0430 is a passive 5:1 resistive divider
on a small breakout: two screw
terminals (`V+`/`V-`) for the battery voltage being measured, and
three pins (`+`/`-`/`S`) that go to the Arduino. On arm, mast, and
antenna, wire `S` to **A0** (see
`docs/diagrams/03_base_mega1_wiring.svg` /
`04_arm_mega2_wiring.svg` / `05_mast_uno3_wiring.svg` — the antenna's
own wiring diagram was never created, see the note in `README.md`'s
"Explicit assumptions" about diagrams), `-` to Arduino `GND`, and `+`
to Arduino `5V` if the module needs its own logic power (some don't —
check your specific board). Double-check `V+`/`V-` polarity before
connecting to a real battery — reversed polarity on a resistive
divider won't necessarily fail safely. Verified in
10.2/10.3/10.4/10.5b below, once each board is flashed and running.

**Base is the exception: two FZ0430s, not one.** The original unit
(`S` to **A0**, same wiring as above) is now explicitly the **drive**
motors' own supply rail. A second, identically-wired FZ0430 (`S` to
**A1**, otherwise the same three connections as the first) reports
the **steering** servos' own supply rail independently - each unit
wired to whichever battery/supply lead actually feeds that half of
the base board, not both to the same source. If both rails are
genuinely powered from the same single battery in your build, both
sensors will simply read the same voltage, which is expected, not a
wiring error - the point of two independent sensors is to catch the
case where they *don't* agree (a voltage drop specific to one rail
under load), not to assume they must differ.

**6.8 DS18B20 temperature sensors** — base, arm, mast, antenna, and
microscope (5 of the first 5 boards; the 6th, power_uno6, gets its
own dedicated sensor list in 6.8d below since it measures something
different - the onboard computer, not its own board enclosure), one
DS18B20 each,
TO-92 package, over 1-Wire rather than I2C or a single analog pin.
**Pinout, looking at the flat face with the three legs pointing down,
left to right: GND, DQ (data), VDD** — double-check this against your
specific sensor's datasheet before wiring; some manufacturers vary.
**VDD** to the Arduino's 5V pin (the DS18B20 tolerates 3.0-5.5V, so
3.3V also works if that's more convenient), **GND** to Arduino GND,
**DQ** to that board's own 1-Wire data pin, which differs per board
rather than following one shared convention: **arm** uses digital pin
**20** (the Mega's dedicated I2C SDA pin, repurposed since nothing
else on that board needs I2C); **base** uses **A4** instead of that
same pin 20, because base's own I2C bus is genuinely in use now (the
PCA9685 steering driver - see 6.8c below), so its DS18B20 moved to A4
(one of the pins steering itself vacated moving to the PCA9685) to
free pin 20 back up; **mast** and **antenna** both use **A4** (the
Uno's own default I2C SDA pin, similarly repurposed, unrelated to
base's own A4 choice above - just the same pin number reused for the
same underlying reason on a different board type); **microscope**
uses digital pin **11** (this board's own digital budget was
different enough - DRV8825 instead of ULN2003 - that 11 was
genuinely spare rather than needing to reclaim an I2C pin at all).
Unlike I2C, 1-Wire has no dedicated hardware pin requirement, so each
of these is a deliberate reuse of whatever pin was actually free on
that specific board, not one rule applied uniformly.

**A real, physical 4.7kΩ resistor is required between DQ and VDD** —
this is not optional, and the Arduino's internal `INPUT_PULLUP` will
not substitute for it (documented as too weak to hold reliable 1-Wire
bus timing). If you're testing on a breadboard, this is one more
component to have on hand beyond the sensor itself; breakout boards
that include the DS18B20 already mounted often have this resistor
built onto the PCB — check yours before adding a second one in series.

Unlike the earlier BMP280 version's one-time "found at boot" check,
this firmware checks for a responding sensor on every single read
cycle (DallasTemperature's own `DEVICE_DISCONNECTED_C`) — a DS18B20
that's unplugged and later reconnected recovers on its own next
cycle, no reset needed. A missing/failed sensor is non-fatal by
design either way — none of these boards' real jobs depend on
temperature telemetry — so a disconnected sensor just means the
temperature field stays at its `-9999` ("sensor not found") sentinel,
not a board that fails to boot.

**6.8b Mast cooling fan** — mast only, not the other three
temperature-sensor boards. A generic N-channel MOSFET driver module
(IRF520-style breakout, or equivalent) switches a 12V-class DC fan
based on the mast's own DS18B20 reading — entirely automatic, no
operator control, no field for it on `MastCommand`.

**This is a low-side switch, and the wiring is easy to get backwards**:
connect the fan's **positive** lead directly to the module's **V+**
(a.k.a. Vin) screw terminal, wired to your external fan supply (not
the Arduino) — this is permanently on, not switched. Connect the
fan's **negative** lead to the module's **V-**/**OUT** terminal — this
is what the MOSFET actually switches to ground. Wiring the fan the
other way round (positive to the switched terminal) won't damage
anything on most of these modules, but the fan will run permanently
regardless of what the firmware commands, defeating the entire point.

On the control side: **GND** to the Arduino's GND, **SIG** to
**A2** (`kFanPwmPin`) — this drives the MOSFET gate directly and is
the only signal connection actually required. **VCC** only powers the
module's own onboard status LED and can be left disconnected if you
don't care about that indicator.

**No hardware PWM pin was available for this** — the mast's entire
PWM budget (D3/D5/D6/D9/D10/D11) was already spent by the yaw/pitch/
lift functions, so A2 runs a software PWM instead
(`updateFanPwm()` in `mast_uno3.ino`, ~50Hz via `millis()`). Nothing
to configure or verify about this beyond the wiring above — it's
firmware-internal, the MOSFET module doesn't know or care whether the
signal it's receiving came from a hardware timer or a software loop.

**The thermostat thresholds are placeholders**
(`kFanOnTempDeciC`/`kFanOffTempDeciC`/`kFanMaxTempDeciC` in
`mast_uno3.ino`) until the real enclosure's thermal behavior is known
on the bench — see `README.md`'s "Explicit assumptions" section for
the full reasoning behind the current values and the hysteresis
design. If the fan never seems to turn on, that may simply mean the
enclosure hasn't reached the placeholder's 35°C threshold yet, not a
wiring fault — check `fan_duty_percent` and `board_temperature_decic`
together in `/rover_mast/state` before assuming something's broken.

**6.8c Base steering: PCA9685 servo driver** — base only. Reverses an
earlier explicit decision documented in `base_mega1.ino`'s own header
comment ("no PCA9685"); this is the one board where that's no longer
true.

**I2C wiring** (Mega, not configurable): **SDA** to pin **20**, **SCL**
to pin **21**. This is why the DS18B20 on this board specifically
lives on **A4** rather than pin 20 the way it briefly did in an
earlier session — pin 20 was reclaimed for genuine I2C once the
PCA9685 needed it, and A4 (one of the pins steering vacated moving to
the PCA9685) took its place.

**CORRECTED: the address is 0x40, the factory default, deliberately
left unjumpered** — an earlier version of this section said 0x70 and
told you to jumper for it; that was a real mistake, caught by a user's
own I2C scan turning up 0x70 on a board that hadn't been jumpered at
all. 0x70 isn't a normal, jumper-configurable slave address on this
chip - it's the PCA9685's built-in "LED All Call" address, which
every unit responds to at power-up regardless of A0-A5 jumper state
(the chip's own datasheet: "the default LED All Call I2C-bus
address... must not be used as a regular I2C-bus slave address since
this address is enabled at power-up"). This project only ever has one
PCA9685, so there's no reason to move it off 0x40 - **leave the
address jumpers unbridged entirely**, `kPca9685Address` in
`base_mega1.ino` matches the factory default directly, nothing to
solder for this specific step.

**Servo wiring**: connect each of the 4 steering servos to PCA9685
channels **0-3** (FL, FR, RL, RR, in that order — `kSteerChannel` in
firmware). Each channel has the same three pins as a direct-pin servo
connection (signal, V+, GND) — the module's own **V+** screw terminal
is a dedicated servo power rail, separate from its **VCC** logic pin.
Wire V+ to its own adequately-rated 5-6V supply (four 40kg-class
digital servos can draw well beyond what the Mega's onboard 5V
regulator safely delivers), sharing ground with the Arduino, never
from the Mega's own 5V pin — this dedicated rail is something the
earlier direct-pin version of this same steering setup never had and
had to call out as a gap to fill separately; the PCA9685 fills it
natively.

Bench-test once wired:
```bash
ros2 run rover_base base_bridge_node --ros-args --params-file src/rover_base/config/base_topology.yaml
ros2 topic pub /cmd_vel geometry_msgs/msg/Twist "{linear: {x: 0.2}, angular: {z: 0.5}}" --once
```
Steering should glide to its new angle over about 0.4s
(`updateSteerEasing()`'s own ramp, not ServoEasing — that library
doesn't work with a PCA9685; see README's "Explicit assumptions" for
why), the same visible easing behavior as before, just produced a
different way. If nothing moves at all, use an I2C scanner sketch
first to confirm the PCA9685 actually responds at 0x40 before assuming
a firmware or servo-calibration problem — if a scan instead turns up
0x70, that's the chip's own built-in All Call address responding
(present regardless of jumpers, see above), not evidence the device
is at 0x70 - don't jumper toward it. A genuinely missing/unpowered
PCA9685 (VCC not connected, or a bad I2C connection) looks identical
to "servos not connected" from the ROS side either way.

**6.8d Power/environmental monitoring Uno #6** — this board's own
sensor suite (2x INA226 behind a TCA9548A mux, 1x DS18B20, 1x cooling
fan), covered here separately from 6.7/6.8 above rather than folded
into those sections, since this board's own use of each sensor
genuinely differs from every other board's: I2C voltage+current
sensing no other board has at all, and a DS18B20 measuring the
onboard computer rather than this board's own enclosure. **UPDATED**
from this board's original FZ0430 + ACS712 design - see README's
"Explicit assumptions" for the full reasoning behind the switch.
**UPDATED AGAIN**: this board itself was originally an Arduino Nano,
swapped for an Uno after repeated hardware trouble with the Nano
units in hand - see README's "Explicit assumptions" for that history
too. No pin numbers below changed as a result of that swap - the Nano
and Uno share every pin this board's own firmware actually uses.

**TCA9548A wiring — SDA/SCL to this board's own A4/A5 (its I2C pins),
VIN to 5V, GND to GND.** Address pins (A0/A1/A2 on the mux itself)
left unconnected for the default 0x70 address - nothing else on this
board's I2C bus needs a different one. **0x70 here is unrelated to
the PCA9685's own 0x70 on the base board** (see README for why that
coincidence is worth knowing about, not worth worrying about) - two
separate chips on two separate Arduinos' own independent I2C buses.

**INA226 x2 wiring** — each unit's VCC to 5V, GND to GND, SDA/SCL to
the TCA9548A's own **SD0/SC0** (battery 1) and **SD1/SC1** (battery
2) channel pins, not directly to this board. Each INA226's own
address pins (A0/A1) left unconnected for the shared default address
(**0x40**) - this is the entire point of routing both through the
mux rather than reconfiguring one unit's address pins: two identical,
unmodified breakouts, isolated onto separate channels instead. Each
INA226's IN+/IN- (or VBUS+/VBUS- depending on the specific breakout's
labeling) goes in series with that battery's own positive lead, not
across it - this is a series current-sensing connection, wired
incorrectly it either reads nothing or reads the wrong thing
entirely, not just inaccurately.

**READ THIS BEFORE TRUSTING ANY CURRENT READING**: the INA226 senses
current via the voltage drop across an external shunt resistor, and
its own shunt-voltage range tops out at ±81.9mV. Many generic INA226
breakouts ship with a fixed 0.1Ω onboard shunt - with that value, the
*maximum* current such a board could ever report before saturating is
81.9mV / 0.1Ω ≈ 0.82A, far below what this rover's batteries need to
measure. `kInaShuntOhms` in `power_uno6.ino` (0.002Ω) is a
placeholder for a higher-current-range shunt value, not a verified
fact about your specific boards. **Check what shunt resistor value
your actual breakout boards have — printed on the PCB near the shunt
component itself on most boards, or in the listing/datasheet if
not — before assuming current readings are meaningful at anything
beyond a rough level.** Voltage readings are unaffected by this
concern; only current is.

**DS18B20 (computer temperature) — same wiring as 6.8 above, on
digital pin 2.** The one genuinely different thing about this
board's copy of the sensor: physically mount it against or near the
onboard computer itself, not this board's own enclosure - the whole
point of this particular sensor on this particular board is what the
computer is doing thermally, not what this small monitoring board
itself is doing.

**Cooling fan (for the computer) — same MOSFET-module wiring as
6.8b/6.8c's own fans, on pin 3 (hardware PWM, this board has no pin
budget pressure at all so no software-PWM workaround is needed).**
Same low-side-switch wiring caveat as every other fan in this
project (fan's positive lead to the module's always-on V+, negative
lead to the switched V-/OUT terminal) - see 6.8b for the full
reasoning if this is the first fan section you're reading.

Bench-test once wired:
```bash
ros2 run rover_power power_bridge_node --ros-args --params-file src/rover_power/config/power_topology.yaml
ros2 topic echo /rover_power/state
```
Unlike every other board, there's no command to publish here first -
this board starts sending `/rover_power/state` on its own, roughly
every 200ms, as soon as it's powered and the bridge node is running.
`battery1_voltage_mv`/`battery2_voltage_mv` should each read close to
that battery's actual voltage on a multimeter; if either reads 0 or
implausible regardless of the real battery, use an I2C scanner first
to confirm both the TCA9548A (0x70) and, with each mux channel
selected in turn, that channel's INA226 (0x40) actually respond,
before assuming a firmware bug - a wiring mistake on the mux side
looks identical to a dead sensor from the ROS side.
`battery1_current_ma`/`battery2_current_ma` should read close to 0
with nothing drawing current from that battery - if a reading is
implausibly small regardless of real load, see the shunt-resistor
warning above before assuming a fault.
`computer_temperature_decic` reading exactly `-9999` means the
DS18B20 didn't respond on its most recent read - same troubleshooting
as 6.8 above. `fan_duty_percent` is entirely automatic against that
same temperature reading, so at room temperature it should read `0`
unless you're actively warming the DS18B20 by hand to test the
thermostat logic.

---

## 7. Sensor and camera setup

**7.1 BNO086 IMU** — confirm the PS0/PS1 protocol-select jumpers are
strapped for **UART-RVC** mode (not I2C/UART/SPI) — see the board's
silkscreen jumper table on the underside. Wire its UART pins to the
Waveshare "USB TO TTL (B)" converter, plug that into USB. No firmware
flashing needed for this device — it free-runs the instant it's powered.

**7.2 L76X GPS** — plug in via USB. No configuration needed at default
settings (9600 baud NMEA output).

**7.3 RPLIDAR C1** — plug in via USB.

**7.4 Cameras** — plug in the main perception camera and the
microscope's USB camera. Confirm both enumerate:
```bash
v4l2-ctl --list-devices    # sudo apt install v4l-utils if missing
```

---

## 8. udev rules — stable `/dev/rover/*` device names

Without this step, devices enumerate as `/dev/ttyACM0`,
`/dev/ttyACM1`, ... in whatever order they happened to power up, which
changes across reboots. Do this once, carefully — it's the step most
worth taking slowly.

**8.1 Identify every device and generate the rules file (recommended).**
```bash
cd ~/mars_rover_ws
python3 tools/identify_rover_devices.py
```
Prompts you to plug in each of the 9 devices (3 Megas, 1 Uno, IMU
adapter, GPS adapter, LIDAR, 2 cameras) one at a time, auto-detects
which new `/dev` entry just appeared, pulls its VID:PID/serial via
`udevadm`, and — after showing you the result and asking for
confirmation — writes a filled-in
`src/rover_bringup/config/udev/99-rover-serial.rules`. Devices can
stay plugged in cumulatively; you only need to unplug everything
before starting. It also automatically detects and handles the "three
identical Mega 2560 boards report the same or an empty serial number"
case described below, falling back to matching on physical USB port
path for just those boards rather than needing you to notice and fix
it by hand.

Needs `udevadm` (part of systemd, present on any Ubuntu install) and
must run **on the rover's own computer** with the real hardware
attached — it exits immediately with a clear message if `udevadm`
isn't found, e.g. if run somewhere else by mistake.

**Manual alternative**, if you'd rather do it by hand or the script
doesn't work for some reason — with **only one device plugged in at a
time**, run:
```bash
udevadm info -a -n /dev/ttyACM0 | grep -E 'idVendor|idProduct|serial|KERNELS' | head -8
```
(substitute `/dev/ttyACM0` for whatever it actually enumerated as, and
for cameras use `/dev/video0` and `SUBSYSTEM=="video4linux"` instead).
Repeat for all 9 devices, noting the values each time, then edit
`src/rover_bringup/config/udev/99-rover-serial.rules` yourself,
replacing every `REPLACE_WITH_...` placeholder with the real values.

**Important caveat for the three Mega 2560 boards** (handled
automatically by the script above, but worth understanding if you're
doing this by hand): many Mega units report an **empty or identical**
`ATTRS{serial}` across boards, since the ATmega16u2 USB-serial bridge
only has a real per-unit serial number if it was explicitly DFU-flashed
with one. If `grep serial` comes back empty or the same for all three,
use the `KERNELS=="..."` physical-USB-port-path value instead (the
shortest one shown) — see the comments in the rules file itself for
exactly how.

**8.2 Install and reload:**
```bash
sudo cp ~/mars_rover_ws/src/rover_bringup/config/udev/99-rover-serial.rules /etc/udev/rules.d/
sudo udevadm control --reload-rules
sudo udevadm trigger
```

**8.3 Verify** — unplug/replug everything, then:
```bash
ls -l /dev/rover/
```
Expect to see `base`, `arm`, `mast`, `microscope`, `imu`, `gps`,
`lidar`, `main_cam`, `microscope_cam` all symlinked to the correct
underlying device. If one's missing, re-check that device's rule line
against `udevadm info` output — a single mismatched character in the
VID:PID or serial won't match.

---

## 9. Xbox 360 controller

**9.1 Connect** (USB cable or a wireless receiver dongle).

**9.2 Verify it's recognized:**
```bash
ls /dev/input/js*     # expect /dev/input/js0
sudo apt install joystick   # if jstest isn't already installed
jstest /dev/input/js0       # move sticks/press buttons, confirm values change
```

**9.3 Verify axis/button indices match the config.** Gamepad mappings
vary by driver — don't assume the defaults in
`src/rover_teleop/config/xbox_teleop.yaml` are correct for your exact
controller/OS combo without checking:
```bash
ros2 run joy joy_node &
ros2 topic echo /joy
```
Move each stick and press each button one at a time, note which array
index changes. If any differ from the yaml (`axis_left_x: 0`,
`button_lb: 4`, etc.), edit that file to match before relying on
teleop.

**9.4 Tuning steering sensitivity.** Steering angle isn't commanded
directly from the stick — it's a consequence of the commanded turn
rate (`angular_z`) and forward speed via the base's kinematics, so
"steering sensitivity" and "turn-rate sensitivity" are the same knob:

| Parameter | File | Default | Effect |
|---|---|---|---|
| `max_angular_radps` | `rover_teleop/config/drive_sensitivity.yaml` | 1.5 rad/s | Full stick/joystick deflection always commands this value; partial deflection scales linearly. Raise for snappier turns, lower for gentler. Applies to both ACKERMANN and POINT_TURN. |
| `deadzone` | same file | 0.12 | How much stick/joystick movement near center is ignored before anything is commanded. |
| `max_steer_deg` | `rover_base/config/base_topology.yaml` | 60.0° | Hard mechanical clamp matching the servos' real travel - not a sensitivity knob, just the ceiling the two above can't exceed. |

`drive_sensitivity.yaml` is a **single shared file**, loaded by both
the physical Xbox controller and the web GUI's on-screen joystick (via
ROS 2's `/**` wildcard node match — see the file itself) — editing it
once changes the feel of both input devices together, restart both to
pick it up. `xbox_teleop.yaml` still holds everything specific to the
Xbox controller itself (button/axis indices, arm/mast/microscope jog
speeds).

No true PID access on the steering servos themselves - they're
standard PWM hobby servos (`base_mega1.ino`'s `setSteerAngle()` computes
a target pulse width and hands it to `updateSteerEasing()`'s own
non-blocking ramp, which smooths the approach to that target but still
just ends up sending pulse widths to the PCA9685, same as writing one
directly would have); whatever position-control loop runs inside the
servo is factory-fixed and isn't exposed over that signal. The drive
motors are open-loop PWM too, for the same reason - the encoders feed
odometry, not a closed-loop speed controller.

---

## 10. First bring-up — one subsystem at a time

Do this before the full `bringup.launch.py` the first time, so a
problem in one subsystem doesn't get lost in a wall of log output from
all of them starting together.

**10.1 URDF sanity check (no hardware required):**
```bash
ros2 launch rover_description display.launch.py
```
RViz should open with the robot model visible; the joint_state_publisher_gui
sliders should move the arm/mast/wheels. You should also see 5 solar
panels and a small antenna on the chassis — both static (no sliders),
since there's no actual antenna/panel-actuation hardware in this
project yet. See README's "Explicit assumptions" for why.

**10.2 Base bridge:**
```bash
ros2 run rover_base base_bridge_node --ros-args --params-file src/rover_base/config/base_topology.yaml
```
This level tests whole-vehicle *kinematics* (`cmd_vel` commands the
vehicle, not one wheel) - use 6.6's raw frames instead if you need to
isolate a single wonky actuator.
```bash
ros2 topic echo /rover_base/board_status   # connected: true, rx_frame_count climbing

# ACKERMANN (default): forward, then a turn
ros2 topic pub /cmd_vel geometry_msgs/msg/Twist "{linear: {x: 0.2}}" --once
ros2 topic pub /cmd_vel geometry_msgs/msg/Twist "{linear: {x: 0.2}, angular: {z: 0.5}}" --once

# POINT_TURN: switch mode, then rotate in place
ros2 topic pub /rover_base/drive_mode rover_msgs/msg/DriveMode "{mode: 1}" --once
ros2 topic pub /cmd_vel geometry_msgs/msg/Twist "{angular: {z: 0.5}}" --once

# STOP: switch mode - motion stops regardless of any Twist still arriving
ros2 topic pub /rover_base/drive_mode rover_msgs/msg/DriveMode "{mode: 2}" --once

ros2 topic echo /rover_base/state          # encoder ticks changing, drive_voltage_mv and steering_voltage_mv both non-zero and plausible, board_temperature_decic a plausible room-temperature-ish value
ros2 topic echo /rover_base/command_echo   # drive_mode + the actual wheel/steer numbers sent
```
`drive_voltage_mv` and `steering_voltage_mv` should each read close to
their own rail's actual battery voltage (×1000 for millivolts) — if
either reads near 0 or near 25000 regardless of the real battery,
check that specific FZ0430's own wiring (drive on A0, steering on A1;
see the base wiring diagram, `docs/diagrams/03_base_mega1_wiring.svg`,
though it predates the second sensor and only shows the original A0
unit) before assuming a firmware bug. Reading the same plausible
voltage on both is expected if both rails share one battery in your
build - the two sensors existing independently doesn't mean they must
disagree. `board_temperature_decic` reading exactly
`-9999` means the DS18B20 didn't respond on its most recent read —
see 6.8 above for the wiring/pull-up requirements before assuming a
firmware bug. Steering servos now glide to each new commanded angle
over about 0.4s (a custom non-blocking ramp in `updateSteerEasing()`,
not ServoEasing - see `README.md`'s "Explicit assumptions" for why
that library doesn't work with the PCA9685 these servos now connect
through) rather than snapping instantly — expected, not lag;
`kSteerEaseSpeedUsPerSec` in `base_mega1.ino` is the tuning knob if
that feels too slow or too fast once real servos are on the bench.

**10.3 Arm bridge** (homes automatically on startup — watch the log
for "sent homing request" then wait for `homed: true`):
```bash
ros2 run rover_arm arm_bridge_node --ros-args --params-file src/rover_arm/config/arm_topology.yaml
ros2 topic echo /rover_arm/state
```
Expect homing to take noticeably longer than it would on a low-ratio
gearbox — the EBA-17-M's 120:1 reduction means real joint speed is
only about 1.9°/s at the firmware's current motor-shaft speed cap (see
README's "Explicit assumptions"), so a joint starting far from its
limit switch can take tens of seconds to reach it. That's expected,
not a sign something's stuck — `homingInProgress` staying `true` for a
while is normal here; only worry if it's still not `homed: true` after
several minutes.

Same kind of FZ0430 voltage check as 10.2 applies here too, though
this board still has just one sensor, not base's own two
(`supply_voltage_mv`
in the state message) — same sensor, same wiring pattern, on this
board's own A0. Same DS18B20 temperature check too
(`board_temperature_decic`), on this board's own 1-Wire data pin (20,
same choice as the base board — this is a Mega).

Startup homing covers all 5 joints in one pass, but each can also be
re-homed individually afterward without disturbing the others:
```bash
ros2 service call /rover_arm/home_joint rover_msgs/srv/HomeJoint "{joint_index: 2}"
ros2 topic echo /rover_arm/state   # joint_homed[2] should go false, then true again once J3 re-triggers its switch
```
Each joint's own homing direction (`kHomingDirection`) and the order
joints home in during an all-5 run (`kHomingOrder`) are independently
configurable in `arm_mega2.ino` — currently PLACEHOLDER values
matching the previous behavior (uniform direction, sequential J1-J5)
pending real mechanical verification; see README's "Arm calibration"
section for the full reasoning behind each. If a joint seeks in the
wrong direction or never triggers its switch, check `kHomingDirection`
for that joint before assuming a wiring fault.

Once a joint's switch trips, it's assigned `kLowerLimitSteps[j]` (that
joint's own real, physical lower bound - PLACEHOLDER, currently
mirroring `kMinDeg[j]` converted to steps) and then drives to absolute
step 0, which this project now defines as that joint's own true
center - not an arbitrary reference point. Once real, distinct values
replace the current placeholders, watch `ros2 topic echo
/rover_arm/state`'s own `joint_position_steps` settle at 0 after this
second move completes, not at the switch's own trigger point - that's
the design working as intended, not a bug. Every joint command (and
preset move) is also clamped to `[kMinDeg, kMaxDeg]` in degrees
(`kStepsPerDegree` converts) before being accepted - bench-verify this
directly by commanding a target well outside a joint's own declared
range and confirming `joint_position_steps` settles at the clamped
bound, not the requested one:
```bash
ros2 topic pub --once /rover_arm/command rover_msgs/msg/ArmCommand "{joint_target_steps: [999999, 0, 0, 0, 0], enable: true}"
ros2 topic echo /rover_arm/state   # joint_position_steps[0] should settle at 160000 (J1's own kMaxDeg=150deg in steps), not 999999
```
`kStepsPerDegree`, `kMinDeg`/`kMaxDeg`, and `kLowerLimitSteps` are all
sourced from numbers this project had already established elsewhere
(`rover_arm/config/arm_topology.yaml`'s own `steps_per_joint_rev`, and
`rover_description/urdf/arm.xacro`'s own joint `<limit>` tags) rather
than freshly guessed here — see README's "Explicit assumptions" for
the full sourcing rationale and the manual-sync obligation this
creates across those files plus the web GUI's own slider bounds.

`ArmState`'s own `drivers_enabled` field is the firmware's actual,
current state, not an echo of what was last commanded — bench-verify
this distinction directly by triggering homing and watching it flip on
its own, with no `enable: true` sent from anywhere:
```bash
ros2 topic echo /rover_arm/state   # watch drivers_enabled
ros2 service call /rover_arm/home_joint rover_msgs/srv/HomeJoint "{joint_index: 0}"
```
`drivers_enabled` should go `true` the moment homing starts, before
any joint command with `enable: true` has been sent. The web GUI's own
arm panel has a single toggle button for this now (`ENABLE DRIVERS` /
`DISABLE DRIVERS (FREE-SPIN)`, replacing what used to be two separate
buttons) — its label and color both follow this same field on every
telemetry update, not a value the browser remembers clicking.

Once calibrated, three predefined poses are reachable directly:
```bash
ros2 service call /rover_arm/arm_preset rover_msgs/srv/ArmPreset "{preset: 1}"   # 0=initial, 1=transport, 2=service
ros2 topic echo /rover_arm/state   # joint_position_steps should move toward that preset's own kXPoseSteps in arm_mega2.ino
```
All three presets currently move to the same all-zero pose — real,
distinct poses for each are pending bench calibration in
`arm_mega2.ino`'s own firmware constants; don't expect the three
buttons to visibly differ yet. Rejected (`accepted: false`) if the arm
isn't fully homed, a homing run is in progress, or the emergency stop
below is currently latched.

The emergency stop can be tested independently of homing status —
it's accepted regardless of whether the arm is homed, mid-homing, or
already e-stopped (engaging it again while already latched is a
harmless no-op):
```bash
ros2 service call /rover_arm/emergency_stop rover_msgs/srv/EmergencyStop "{engage: true}"
ros2 topic echo /rover_arm/state   # estop_active should read true; joint_position_steps should stop changing shortly after (a controlled deceleration, not instant)
ros2 service call /rover_arm/emergency_stop rover_msgs/srv/EmergencyStop "{engage: false}"
```
While latched, regular joint commands and preset requests are both
silently ignored (not queued for later) — send a small joint move or a
preset request while `estop_active: true` and confirm
`joint_position_steps` genuinely doesn't change, then clear it and
confirm the same command now works, to bench-verify the gate is
actually wired correctly before relying on it for real. **The drivers
stay energized throughout an e-stop, on purpose** — see README's "Arm
emergency stop" section for the full safety reasoning before assuming
this is a bug; a real power-cutting e-stop would need different
firmware, not just a different comment.

The web GUI's arm panel has all of the above as buttons (`CALIBRATE
J1`-`J5`, `CALIBRATE ALL 5`, `INITIAL POSITION`, `TRANSPORT POSITION`,
`SERVICE POSITION`, `E-STOP`, `CLEAR E-STOP`) — see README's "Arm
calibration" and "Arm emergency stop" sections for the full picture.

**10.4 Mast bridge** (yaw/pitch now home automatically on startup —
same pattern as the arm, watch the log for "sent homing request to
mast Uno" then wait for `homed: true`; the lift is unaffected and
works immediately regardless of homing state):
```bash
ros2 run rover_mast mast_bridge_node --ros-args --params-file src/rover_mast/config/mast_topology.yaml
ros2 topic echo /rover_mast/state
```
Same FZ0430 voltage check applies here too, and the same DS18B20
temperature check (`board_temperature_decic`), on this board's own
1-Wire data pin (A4 - this is an Uno). `fan_duty_percent` in the same
state message is worth a glance too - entirely automatic against that
same temperature reading, so on a bench-top test at room temperature
it should read `0` (fan off) unless you're actively warming the
DS18B20 by hand to test the thermostat logic; see 6.8b for wiring and
the placeholder threshold values. Watch `yaw_limit_triggered`/
`pitch_limit_triggered` in the state message while homing runs — each
should flip briefly to `true` right as that axis reaches its switch,
then homing moves on to the next axis (or finishes, for pitch). Pitch's
real range is ±180° (confirmed against hardware - not the ±60° an
earlier placeholder assumed), so don't be surprised if that axis takes
noticeably longer to reach its switch than yaw does from a similar
starting position.

Once a given axis's limit switch triggers, its position is set to that
axis's minimum (-170° yaw, -180° pitch), not zero - the switch is
physically at that extreme, not center. Watch both axes then drive
from there back toward 0°/0° on their own, without any command from
you - this is still part of calibration, not a separate step, and
`homed: true` only appears once both axes actually arrive there and
the drivers disable themselves (watch `driver_enabled` stay `true`
through this move, then go `false` at the end). Yaw/pitch commands are
silently ignored the whole time, and won't do anything afterward
either until re-enabled:
```bash
ros2 topic pub -r 10 /rover_mast/command rover_msgs/msg/MastCommand "{head_yaw_decideg: 0, head_pitch_decideg: 0, lift_mode: 0, driver_enable: true}"
```

**10.5 Microscope (bridge + camera):**
```bash
ros2 launch rover_microscope microscope.launch.py
ros2 topic echo /rover_microscope/state
ros2 topic hz /rover_microscope/image/compressed   # confirm frames are flowing
```
The DRV8825 focus/zoom driver starts disabled (`driver_enabled: false`
in the state message) — nothing will move until a command explicitly
enables it (the web GUI's `CLOSE DRIVER (ENABLE)` button, or
`driver_enable: true` in a manual `MicroscopeCommand`). Before
powering this up for the first time: confirm the 24BYJ-48's
center-tap wire is genuinely disconnected, not just unused — see
`firmware/microscope_uno4/microscope_uno4.ino`'s header comment for
why this matters (a real short risk, not just a "won't work" mistake).
The lens cover now glides open/closed over about 1 second
(a custom non-blocking ramp, `updateCoverEasing()` - no longer
ServoEasing, see README's "Explicit assumptions" for why) rather than
snapping instantly — `kCoverEaseSpeedDegPerSec`
in that same file is the tuning knob. Open and close are now two
separate buttons in the web GUI (`OPEN COVER`/`CLOSE COVER`), not one
toggle — click each to bench-test both directions independently.

**10.5b Antenna gimbal** (azimuth/elevation home automatically on
startup — same pattern as the mast, watch the log for "sent homing
request to antenna gimbal Uno" then wait for `homed: true`):
```bash
ros2 run rover_antenna antenna_bridge_node --ros-args --params-file src/rover_antenna/config/antenna_topology.yaml
ros2 topic echo /rover_antenna/state
```
Same FZ0430 voltage check as 10.2 applies here too, and the same
DS18B20 temperature check (`board_temperature_decic`), on this board's
own 1-Wire data pin (A4 - this is an Uno). Unlike the mast,
homing here is a single pass with no follow-on move-to-center step —
each calibration switch is assumed mounted at that axis's own
operational minimum (15° azimuth, 0° elevation), so `homed: true`
appears as soon as both switches are found, not after a further
move. `driver_enabled` starts `true` (homing needs the drivers
energized) but azimuth/elevation commands are ignored until `homed`
is `true` — same reasoning as the mast's own gating (see
`rover_antenna/rover_antenna/antenna_protocol.py`): the bridge sends
command frames continuously at its own control rate once past its
one-shot homing request, and applying a stale/default command
unconditionally during homing would strand a stepper mid-seek.

**10.6 Sensors (IMU, GPS, main camera):**
```bash
ros2 launch rover_sensors sensors.launch.py
ros2 topic echo /rover_sensors/imu/data
ros2 topic echo /rover_sensors/gps/fix
ros2 topic hz /rover_sensors/main_camera/image/compressed
```
GPS needs a sky view to get a fix — `fix.status.status` will read
`-1` (no fix) indoors, which is expected, not a bug.

**10.7 LIDAR:**
```bash
ros2 launch rplidar_ros rplidar_c1_launch.py serial_port:=/dev/rover/lidar
ros2 topic hz /scan
```

**10.8 Teleop:**
```bash
# Terminal 1 (if not already running from 10.2)
ros2 run rover_base base_bridge_node --ros-args --params-file src/rover_base/config/base_topology.yaml

# Terminal 2
ros2 launch rover_teleop xbox_teleop.launch.py
ros2 topic echo /rover_teleop/mode   # should print DRIVE
```

Everything below needs the deadman held - nothing moves without it:

| Do this | Expect |
|---|---|
| Hold **RB**, push left stick forward/back | Drives forward/back (ACKERMANN) |
| Hold **RB**, push left stick left/right | Turns |
| Release **RB** | Immediate stop, in any mode |
| Tap **X** | Toggles ACKERMANN ↔ POINT-TURN |
| In POINT-TURN, hold **RB** + push stick left/right | Rotates in place (forward/back on the stick does nothing here - expected, see README) |
| Tap **Y** | Forces STOP immediately |
| Tap **X** after STOP | Resumes at ACKERMANN (Y is deliberately one-way, not a toggle) |

Watch a second/third terminal to confirm the controller and the
bridge agree with each other:
```bash
ros2 topic echo /rover_teleop/mode                  # DRIVE/ARM/MAST/MICROSCOPE/ANTENNA (subsystem)
ros2 topic echo /rover_teleop/drive_geometry_mode   # ACKERMANN/POINT_TURN/STOP, as teleop sees it
ros2 topic echo /rover_base/command_echo            # ground truth: what's actually being sent to the Mega
```
Or skip the terminals entirely and use the web GUI instead (`ros2
launch rover_web_gui web_gui.launch.py`, then browse to
`http://<rover-host>:8080/`) - the DRIVE panel's mode buttons and
board-status lamps show all of this live.

**10.9 Web GUI:**
```bash
ros2 launch rover_web_gui web_gui.launch.py
```
Open `http://<rover-host>:8080/` in a browser. Board status lamps
should light up as the other subsystems come online; the microscope
tab link opens `/microscope` in a new tab. The arm panel's
`CALIBRATE J1`-`J5` / `CALIBRATE ALL 5` / `INITIAL POSITION` /
`TRANSPORT POSITION` / `SERVICE POSITION` / `E-STOP` / `CLEAR E-STOP`
buttons need
`rover_arm_bridge` running (10.3) — the status line under them shows
each request's result message. The mast panel's `RETURN HOME` /
`TRANSPORT POSITION` buttons work the same way against
`rover_mast_bridge` (10.4) - if `TRANSPORT POSITION` sends the head to
somewhere unexpected, check `rover_mast/config/mast_topology.yaml`'s
`transport_head_yaw_deg`/`transport_head_pitch_deg` values rather than
assume it's a bug; they're placeholders (0.0/0.0) until bench-tuned.
The antenna panel's azimuth/elevation sliders need `rover_antenna_bridge`
running (10.5b) - like the microscope, its `CLOSE DRIVER (ENABLE)`
button needs pressing before the sliders do anything, though for a
different reason (the antenna's own homing sequence disables nothing
automatically the way the mast's used to - it simply never enables
manual commands until `homed` is true).

**10.10 Wheel odometry + sensor fusion** (runs automatically as part
of the full bringup, but worth checking in isolation first). Standing
alone, `odometry_node` still publishes on `/odom` directly — the
`wheel_odom` remap and EKF fusion only happen when launched through
`bringup.launch.py` or `localization.launch.py`:
```bash
ros2 run rover_base odometry_node --ros-args --params-file src/rover_base/config/base_topology.yaml
ros2 topic echo /odom
```
Drive forward (Level 2/3 of the motor-testing walkthrough above) and
confirm `pose.pose.position.x` increases; turn in place (POINT_TURN)
and confirm `pose.pose.orientation` changes while position stays put.

**10.10b Full fusion pipeline** (wheel odometry + IMU via the local
EKF, plus GPS conversion services):
```bash
ros2 launch rover_navigation localization.launch.py
ros2 topic echo /odom          # now the EKF's fused output, not raw wheel_odom
ros2 topic echo /odometry/gps  # only publishes once the GPS has a fix - try this outdoors
```
Compare `/odom`'s motion against the raw `/wheel_odom` topic while
turning — the fused estimate should track it closely but noticeably
smoother, especially right after a turn. If `/fromLL` and `/toLL`
don't show up in `ros2 service list`, `navsat_transform_node` isn't
running — check its terminal output for GPS fix errors.

**10.11 SLAM and Navigation** — needs the LIDAR (10.7) and fusion
(10.10b) both working first:
```bash
# Mapping: drive the rover around, then save the map
ros2 launch rover_bringup bringup.launch.py use_slam:=true
ros2 run nav2_map_server map_saver_cli -f ~/mars_rover_ws/src/rover_navigation/maps/my_map

# Navigation: autonomous driving against that saved map
ros2 launch rover_bringup bringup.launch.py use_navigation:=true \
    nav_map:=$HOME/mars_rover_ws/src/rover_navigation/maps/my_map.yaml
```
Open `rover_navigation/rviz/navigation.rviz` in RViz to watch the map/
costmaps build or to send navigation goals ("2D Pose Estimate" to
localize, "Nav2 Goal" to send a destination). Outdoors, with a GPS fix,
you can also send a goal by coordinate instead:
```bash
ros2 run rover_navigation gps_goal.py 42.4373 -86.9436
```
Full walkthrough and architecture are in the README's
"Navigation (SLAM + Nav2 + sensor fusion)" section.

**10.12 MoveIt2 arm planning** — needs the arm bridge (10.3) already
homed (`ArmState.homed: true`) first; goals are rejected otherwise:
```bash
ros2 launch rover_bringup bringup.launch.py use_moveit:=true
ros2 launch rover_arm_moveit_config moveit_rviz.launch.py
```
In RViz's MotionPlanning panel, drag the interactive marker at the
arm's tip, **Plan**, then **Execute**. Watch `ros2 topic echo
/rover_arm/command` in a separate terminal while it executes — you
should see `joint_target_steps` update through a sequence of
intermediate values as the trajectory plays out, not jump straight
from start to goal. If `Execute` does nothing, check
`ros2 action list` for `/arm_controller/follow_joint_trajectory` — if
it's missing, `trajectory_action_server` isn't running (needs
`use_moveit:=true`, not just `move_group` on its own).

---

## 11. Full bring-up

Once every subsystem above checks out individually:
```bash
ros2 launch rover_bringup bringup.launch.py
```
Useful flags for bench-testing without full hardware:
```bash
ros2 launch rover_bringup bringup.launch.py use_teleop:=false use_lidar:=false
```
(`use_web_gui:=false` is also available. `use_slam:=true` or
`use_navigation:=true nav_map:=...` add SLAM/Nav2 on top - see 10.11
above; don't set both at once. `use_moveit:=true` adds arm motion
planning - see 10.12 - independent of SLAM/navigation, combine freely.)

---

## 12. Troubleshooting quick-reference

| Symptom | Likely cause | Where to look |
|---|---|---|
| `board_status.connected: false` for one board | Wrong `/dev/rover/*` symlink, or that board's firmware wasn't flashed | Step 6 (firmware), Step 8 (udev) |
| `board_status.connected: true` but `rx_frame_count` stuck at 0 (or a board-status lamp shows amber/"warn" instead of plain green) | Either (a) `/dev/rover/X` resolved to the *wrong* physically-identical board (esp. the two Megas, or any of the now-four Unos sharing 2341:0043 - mast, microscope, antenna, `power_uno6`; see the udev serial-collision caveats), which opens fine but never recognizes that board's frame types (surfacing as climbing `checksum_error_count`, the lamp's own "bad" counter), or (b) the board was still finishing its own auto-reset (opening a serial connection resets Arduino-family boards) when the bridge sent its first frame | `tools/raw_serial_probe.py <port>` to test the board directly, independent of ROS — this still works for `power_uno6` even though it sends a 'D' frame that board ignores, since it also proactively sends its own state frames on a timer regardless of what arrives; confirm the symlink with `ls -l /dev/rover/*` against `ls /dev/ttyACM* /dev/ttyUSB*` with only that board plugged in. (b) should self-resolve automatically now — `SerialLink` has a `boot_grace_sec` (default 2.0s) that no-ops I/O until the board's had time to reboot; raise it in that board's config yaml if 2s isn't enough for your bootloader |
| Arm never reports `homed: true` | A calibration switch not wired/triggering, or `home_on_startup` never sent | Check `arm_mega2` wiring against `firmware/arm_mega2/arm_mega2.ino`'s pin comments |
| Arm: `homed: true`, some joints move and others don't | Since J1-J3 moved to TB6600 (each with its own enable pin) and J4/J5 stayed on A4988 (one shared enable pin), a wiring mistake on any *one* of those four enable connections now only affects the joint(s) behind it, not the whole arm | Check `kTb6600EnablePin[3]` (pins 13/14/15, one per J1/J2/J3) and `kA4988EnablePin` (pin 12, shared by J4/J5) against actual wiring; measure each driver's own ENA/EN pin directly rather than assuming they're all still tied together the way they used to be |
| Mast never reports `homed: true` | Same as the arm above, but for the yaw/pitch calibration switches specifically (added when the mast moved to an Uno) | Check `mast_uno3` wiring against `firmware/mast_uno3/mast_uno3.ino`'s pin comments; `ros2 topic echo /rover_mast/state` for `yaw_limit_triggered`/`pitch_limit_triggered` — neither ever flipping `true` while the head physically reaches its travel limits means that switch isn't wired/triggering |
| `board_temperature_decic` reads `-9999` on base/arm/mast/antenna | DS18B20 didn't respond on its most recent read - most likely the external 4.7kΩ pull-up resistor is missing (this is not optional and the Arduino's internal pull-ups cannot substitute), or DQ/GND/VDD are swapped | Check the 4.7kΩ pull-up is actually present between DQ and VDD; verify pinout against the sensor's own datasheet (GND/DQ/VDD left-to-right facing the flat TO-92 face is common but not universal); see 6.8 |
| Mast fan runs constantly regardless of temperature | Fan wired to the module's always-on V+ terminal instead of the switched V-/OUT terminal (an easy mix-up on a low-side switch design), or `board_temperature_decic` is stuck at `-9999` (the deliberate fail-toward-running behavior on sensor failure, not a fan bug - see 6.8b/README) | Check the fan's positive lead is on V+ and negative on V-/OUT, not reversed; check `board_temperature_decic` isn't `-9999` before assuming the fan control logic itself is wrong |
| Mast fan never turns on even when the board feels warm | `fan_duty_percent` reading `0` while `board_temperature_decic` is below the placeholder 35°C threshold is expected, not a bug - "feels warm to the touch" and "35.0°C" aren't the same thing | Check the actual `board_temperature_decic` value against `kFanOnTempDeciC` in `mast_uno3.ino` before assuming a wiring fault; bench-tune the threshold once real enclosure behavior is known |
| I2C scan on the base's bus shows `0x70` (and possibly a reserved-range address like `0x03`) | `0x70` is the PCA9685's own built-in "All Call" address, present on every unit at power-up regardless of jumper state - seeing it does NOT mean the board is jumpered to 0x70, and does not mean anything is wrong. A reserved-range hit (`0x00`-`0x07`) is very likely a scanner artifact, not a second real device | No action needed - the PCA9685 should be left at its factory-default 0x40 (unjumpered) either way; see 6.8c |
| `battery1_voltage_mv`/`battery2_voltage_mv` reads 0 or implausible regardless of the real battery | Either that battery's INA226 isn't responding (wiring, or the wrong mux channel), or the TCA9548A itself isn't responding | Use an I2C scanner to confirm the TCA9548A answers at 0x70, then - with each mux channel selected in turn - that channel's INA226 answers at 0x40; a wiring mistake anywhere in that chain looks identical to a dead sensor from the ROS side |
| `battery1_current_ma`/`battery2_current_ma` never reads more than a small value regardless of real load | Very likely the shunt-resistor concern in 6.8d, not a fault - a common 0.1Ω onboard shunt caps the INA226's measurable current at ~0.82A, far below real battery current | Check what shunt resistor value the actual breakout board has (usually printed on the PCB) before assuming a firmware bug; see 6.8d and README's "Explicit assumptions" |
| Mast `homed: true`, yaw/pitch commands silently do nothing | Just finished calibration - it disables the drivers automatically once both axes reach true zero | Check `driver_enabled` in the state message; if `false`, send a command with `driver_enable: true` (or the web GUI's `CLOSE DRIVER (ENABLE)`) |
| Mast lift doesn't move | Limit switches wired backwards (already at a triggered state), or the HW-039's enable pin isn't wired | `mast_uno3.ino` — check `stowedLimitTriggered()`/`erectLimitTriggered()` against actual switch wiring; confirm `kLiftEnPin` reads HIGH (R_EN/L_EN tied together on the HW-039 module) |
| Mast yaw/pitch: `homed: true`, drivers otherwise seem fine, but nothing moves | TB6600's ENA input wired wrong polarity, or ENA+ not actually tied to +5V | `kHeadEnablePin` (pin 13) is driven LOW = enabled, assuming standard common-anode wiring (ENA+ to +5V, ENA- to the Arduino pin) — if wired common-cathode instead this is backwards; measure the actual voltage across ENA+/ENA- on each TB6600 while the board is running to confirm which convention it's actually wired for |
| Microscope focus/zoom motor runs hot, stalls, or the DRV8825 gets hot fast | 24BYJ-48's center-tap wire is still connected somewhere (grounded, or tied to the driver) instead of left disconnected | Physically verify only the 4 coil-end wires reach the driver's A1/A2/B1/B2 - see `microscope_uno4.ino`'s header comment; disconnect power immediately if this is suspected, this is a real short risk, not just a performance issue |
| Microscope focus/zoom doesn't move, `driver_enabled: false` in the state message | Nothing has enabled the driver yet - it starts disabled at boot | Web GUI: click `CLOSE DRIVER (ENABLE)`; manually: send a `MicroscopeCommand` with `driver_enable: true` |
| Antenna azimuth/elevation don't move, `homed: true` in the state message | Nothing has enabled the drivers via a command yet - they start enabled internally for homing's own sake, but `antenna_uno5.ino` ignores every command's `driver_enable` value until `homed` is true, so the very first command after that needs to explicitly ask for it | Web GUI: click `CLOSE DRIVER (ENABLE)`; manually: send an `AntennaCommand` with `driver_enable: true` |
| Antenna never reports `homed: true` | Same as the arm/mast above, but for the azimuth/elevation calibration switches specifically | Check `antenna_uno5` wiring against `firmware/antenna_uno5/antenna_uno5.ino`'s pin comments; `ros2 topic echo /rover_antenna/state` for `azimuth_limit_triggered`/`elevation_limit_triggered` - neither ever flipping `true` while the gimbal physically reaches its travel limits means that switch isn't wired/triggering |
| Camera topic publishes nothing | Wrong `camera_device` path, or camera needs a moment after plug-in | `v4l2-ctl --list-devices`, confirm the udev symlink from step 8 |
| Camera log shows GStreamer warnings ("unable to start pipeline") followed by a `CV_IMAGES`/`icvExtractPattern` "can't find starting number" error | Not actually a missing-camera problem - OpenCV's backend auto-detection tries FFMPEG then GStreamer before ever reaching V4L2, and a udev symlink can fail against those two even though it's a perfectly ordinary V4L2 device, cascading all the way to `CV_IMAGES` (meant for numbered image-file sequences, not devices) | Fixed in `main_camera_node.py`/`camera_publisher_node.py` by requesting `cv2.CAP_V4L2` explicitly rather than relying on auto-detection - if you see this exact cascade elsewhere (e.g. a new camera node), the fix is the same |
| MoveIt goal rejected immediately, no execution attempted | Arm hasn't finished homing yet, or `trajectory_action_server` isn't running | `ros2 topic echo /rover_arm/state` for `homed: true`; `ros2 action list` for `/arm_controller/follow_joint_trajectory` |
| "Unable to identify any set of controllers" from `move_group` | `moveit_controllers.yaml`'s controller name/`action_ns` doesn't match what `trajectory_action_server` actually serves | Confirm the action name printed by `ros2 action list` is exactly `arm_controller/follow_joint_trajectory` |
| `arm_bridge_node` crashes with `RoverFrameError: field 0 is not an int` (or similar) | Fixed — was a real bug, not a config issue. rclpy backs fixed-size numeric array message fields (`ArmCommand`'s `int32[5] joint_target_steps`) with `numpy.ndarray`; its elements are `numpy.int32`, not Python `int`, and used to reach the protocol layer's strict int-only check unconverted. If you see this again on a *different* field, the fix is the same: cast to `int(...)` where the array field's value is first read out of the message, not just where it's encoded. |
| A board's own status lamp never goes green *or* amber at all — not "connected with bad data", just no data, ever, right after adding or pulling in a new message/service type (e.g. `rover_msgs/srv/EmergencyStop`, `rover_msgs/srv/ArmPreset`) | The bridge node that `import`s the new type crashed on startup, before publishing anything — a brand-new message/service type needs a rebuild to actually generate its Python bindings; the node's own `from rover_msgs.srv import ...` (or `.msg import`) fails with an `ImportError` until then, and the whole process exits immediately | Check that specific node's own console/log output first — an import traceback there confirms this directly. `colcon build --symlink-install`, re-source, relaunch. This isn't arm-specific — any board's bridge node hits the same failure mode after any new message/service type is added, if launched before the next rebuild |
| A bridge node logs normally at startup, then goes completely silent forever — no error, no crash, no further output at all, `board_status` never published (lamp stuck red) — especially right around a slow firmware operation (a real example: the arm mid-homing, against its own 120:1 gearbox) | FIXED — was a real, project-wide bug, not this board's own fault: `SerialLink`'s underlying connection had a read timeout but no write one before this fix, so a write could block the calling thread indefinitely if the board's own tiny hardware serial buffer filled faster than its firmware was draining it. Silence with no error is the actual signature of this - a thread stuck on a blocking syscall produces neither | Confirm you're on a build that includes `write_timeout` in `rover_protocol/serial_link.py`'s own `SerialLink.__init__()` (see README's "Explicit assumptions" for the full incident) - `colcon build --symlink-install` after pulling in a fix, then relaunch. If it recurs even on a fixed build, that's a different, new issue - open with the actual log output, not a description of the symptom |
| A board's own lamp never turns green *and* its own telemetry panel never shows anything, even though `ros2 topic echo` on that board's own `state`/`board_status` topics shows real, valid messages actively streaming, and the browser's own dev-tools console shows no errors at all — specifically the base and arm panels, with every other board's own panel looking fine | FIXED — was a real, project-wide bug in `rover_web_gui`, not that board's own bridge node or firmware at all (both fully exonerated by the exact `ros2 topic echo` + browser-console checks described in the symptom column - see README's "Explicit assumptions" for the full incident). `ros_bridge.py`'s own `_on_base_state()`/`_on_arm_state()` read fixed-size ROS array fields (base's `encoder_ticks`, arm's `joint_position_steps` and others) via a bare `list(msg.field)`, which rclpy backs with `numpy.ndarray` - producing `numpy.int32`/`numpy.bool_` elements that `json.dumps()` cannot serialize at all. That exception was previously uncaught inside `server.py`'s own combined, single-task telemetry sender, silently killing telemetry for **every** board at once, not just the one with the bad field - the other boards only looked fine because the browser was still displaying their own last successfully-sent values, frozen, never actually still updating. This is exactly why the browser console stayed clean: the failure happened server-side, in Python, inside an `asyncio` task whose own uncaught exceptions never reach the browser at all | Confirm you're on a build with the per-element casts in `ros_bridge.py`'s own `_on_base_state()`/`_on_arm_state()` (`[int(t) for t in ...]`, not `list(...)` directly) and the defensive per-tick exception handling in `server.py`'s own `_telemetry_sender()` - `colcon build --symlink-install`, relaunch. If a *different* board's own telemetry silently stops working after this fix, check that board's own state message for any array field first (`grep -E '^\w+\[' src/rover_msgs/msg/<Board>State.msg`) - the same bug class applies to any array field on any board, not just these original two, though `_telemetry_sender()`'s own hardening should now at least keep it from taking every other board down with it |
| GPS `fix.status.status` always `-1` | No sky view (expected indoors), or wrong baud | Move outdoors; confirm `serial_baud: 9600` in `sensors.yaml` matches the module |
| Xbox teleop does nothing | Deadman (RB) not held, or axis/button indices wrong for your controller | Step 9.3 |
| Web GUI loads but shows no telemetry | ROS bridge not connected — check the `web_gui_node` terminal for errors | Confirm other subsystems are actually running/publishing first |
| `colcon build` errors | See the table in Step 4 | |

---

## 13. Next steps

Once bring-up is solid, see the "Known gaps / natural next steps"
section of `README.md` — arm IK, wheel odometry, and Nav2 integration
are the natural follow-ons, none of which block using the rover
manually via the web GUI or Xbox controller today.

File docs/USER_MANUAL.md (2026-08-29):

# Mars Rover User Manual

This is the day-to-day operating guide: starting the rover up, driving
it, using the arm/mast/microscope, and reading what it's telling you.

It assumes the rover is **already built and configured** — firmware
flashed, udev rules installed, the ROS 2 workspace built. If any of
that isn't done yet, start with `docs/INSTALL.md` instead; this manual
picks up where that one leaves off. For the underlying engineering
detail behind anything mentioned here (exact topic names, kinematics,
design decisions), see `README.md`.

---

## Before you operate it: safety

This rover has real motors, servos, and steppers that move with real
force. A few things worth internalizing before the first power-up:

- **The deadman switch matters.** Driving from the Xbox controller
  requires holding **RB** the whole time — in *every* control mode,
  not just DRIVE. Release it and commands stop being sent. This is
  deliberate, not a bug: it's the difference between "the controller
  is in your hands" and "the controller fell on the floor still
  pointed at a stick."
- **Every board has its own watchdog.** If commands stop arriving
  (dropped connection, closed terminal, crashed node) for about half a
  second to a second depending on the board, that board stops or holds
  position on its own — you don't have to trigger a stop manually for
  a dropped link to be safe, but don't rely on it as your *primary*
  stopping method either.
- **STOP mode is the fastest way to stop driving.** Web GUI: the red
  `STOP` button. Xbox controller: **Y**, from any drive mode, at any
  time — it overrides everything else immediately. Press **X** to
  resume (STOP doesn't clear itself).
- **The arm won't move until it's calibrated**, and that's
  intentional — see [Arm](#arm) below. Don't fight this by trying to
  force movement before `homed: true`; it's a safety gate, not a bug.
- **The mast moves on its own right after calibration finishes** —
  each axis drives from its limit switch (at that axis's extreme)
  back to center, then its drivers disable themselves. Expected, not a
  malfunction — see [Mast](#mast) below — but worth knowing before it
  happens the first time so it isn't mistaken for something going wrong.
- **Stay clear of moving parts** during arm motion, mast erect/stow,
  and while driving — obvious, but worth saying once, plainly, before
  the rest of this document gets into the details.

---

## 1. Overview

| Subsystem | What it does | Controlled via |
|---|---|---|
| **Base** | 6-wheel drive, 4-corner steering | Xbox controller, web GUI joystick |
| **Arm** | 5-axis manipulator | Web GUI (sliders + buttons), Xbox controller, optionally MoveIt2 |
| **Mast** | Pan/tilt camera head + erect/stow lift | Web GUI, Xbox controller |
| **Microscope** | Focus/zoom, LED, lens cover, snapshot/recording | Web GUI, Xbox controller |
| **Antenna** | High-gain-antenna gimbal (azimuth/elevation pointing) | Web GUI, Xbox controller |
| **Sensors** | IMU, GPS, LIDAR, main + microscope cameras | Automatic once launched |
| **Navigation** | SLAM mapping, autonomous driving, GPS waypoints | `ros2` commands (advanced) |

Two ways to control the rover, and you can use either or both at once:

- **Xbox controller** — full manual control, all subsystems, one
  device. **LB** cycles which subsystem the controller is currently
  driving: `DRIVE → ARM → MAST → MICROSCOPE → ANTENNA → DRIVE`.
- **Web GUI** — open `http://<rover-host>:8080/` in a browser. Buttons
  and sliders for every subsystem, plus live telemetry. No controller
  needed.

Both talk to the same underlying rover at the same time — driving from
the controller while watching telemetry in the browser is the normal
way to work.

---

## 2. Starting up

### 2.1 Power on

Power on the base, arm, mast, and microscope boards per your own
wiring, then power on (or SSH into) the host computer. Give the
Arduino boards a moment — they auto-reset when the host's serial
connections first open, which the software already accounts for
(`boot_grace_sec` in each board's config), but it's still worth a
few seconds before expecting a response.

### 2.2 Launch

The everyday case — driving, arm, mast, microscope, and sensors, no
mapping or autonomy:

```bash
ros2 launch rover_bringup bringup.launch.py
```

Common variations:

```bash
# Bench-testing without the physical LIDAR or Xbox controller plugged in
ros2 launch rover_bringup bringup.launch.py use_lidar:=false use_teleop:=false

# Building a map of a new area (see Navigation, below)
ros2 launch rover_bringup bringup.launch.py use_slam:=true

# Driving autonomously against a map saved from a previous SLAM session
ros2 launch rover_bringup bringup.launch.py use_navigation:=true nav_map:=/path/to/map.yaml

# Arm motion planning via MoveIt2, on top of manual arm control
ros2 launch rover_bringup bringup.launch.py use_moveit:=true
```

These combine freely except `use_slam` and `use_navigation` — don't
set both at once (build a map, save it, *then* navigate against it).

### 2.3 What to expect while it comes up

- **Arm and mast home themselves automatically.** Watch for "sent
  homing request" in the terminal log from each. This can take a
  while — the arm's actuators are heavily geared, so a joint starting
  far from its limit switch can take tens of seconds; that's normal,
  not stuck. Don't send arm or mast movement commands until homing
  finishes (they'd be silently ignored anyway — see
  [Arm](#arm)/[Mast](#mast)). The mast specifically drives from each
  axis's limit switch back to center as part of this same process —
  `homed` doesn't actually go true until it arrives there and disables
  its own drivers, not the instant a switch triggers — so expect a few
  seconds of movement before it reports homed, then press
  `CLOSE DRIVER (ENABLE)` in the web GUI before expecting the mast
  sliders to do anything.
- **The antenna gimbal also homes itself automatically**, simpler than
  the mast's own sequence: each axis's calibration switch sits at that
  axis's real operational minimum, so `homed` goes true as soon as
  both switches are found, with no follow-on movement. Its drivers
  start enabled (homing needs them energized) but won't accept manual
  commands until `homed` is true, and — like the microscope — need
  `CLOSE DRIVER (ENABLE)` pressed before the azimuth/elevation sliders
  do anything.
- **The microscope's focus driver starts disabled** and the lens cover
  starts closed — both by design, not homing. Enable/open them
  explicitly once you're ready to use the microscope.
- **Board status should go green.** Web GUI: status lamps at the top
  light up as each board's serial link comes online. If one stays red
  for more than a few seconds after power-on, see
  [Troubleshooting](#troubleshooting).

### 2.4 Open the web GUI

```
http://<rover-host>:8080/
```

(Replace `<rover-host>` with the rover's hostname or IP — `localhost`
if you're on the rover's own machine.) The microscope also has its own
dedicated page at `/microscope`, with the same controls as the main
dashboard's microscope panel, useful for a full-screen camera view.

---

## 3. Shutting down

1. Bring the arm and mast back to a safe, stowed position first (see
   [Arm](#arm) → Return Home, [Mast](#mast) → Stow) — don't just kill
   power with the arm extended or the mast erect.
2. `Ctrl-C` the `bringup.launch.py` terminal, or stop it however you
   normally manage long-running processes. Every bridge node sends an
   explicit stop command to its board as it shuts down — you don't
   need to manually zero anything first.
3. Power off the boards.

---

## 4. Operating the rover

### Driving

Three drive modes, switched independently of whatever's currently
commanding the rover:

| Mode | What it does |
|---|---|
| **ACKERMANN** | Normal driving — forward/back plus a turn, corner wheels steer through an arc like a car |
| **POINT-TURN** | Rotates about the rover's own center, no forward motion |
| **STOP** | Unconditional stop — ignores any drive input until switched out of |

**Web GUI**: `ACKERMANN` / `POINT-TURN` / `STOP` buttons at the top of
the drive panel, plus a draggable on-screen joystick — drag to set
speed and turn rate proportionally, release to snap back to zero. The
joystick is visually and functionally disabled while in STOP mode.

**Xbox controller** (in DRIVE mode — press LB until the controller is
in DRIVE): left stick Y = throttle, left stick X = turn, **X** toggles
ACKERMANN ↔ POINT-TURN, **Y** forces STOP (press **X** to resume).
Remember: **RB must be held** for any of this to reach the rover.

Both the controller and the web GUI joystick share one speed/turn-rate
ceiling and deadzone (`rover_teleop/config/drive_sensitivity.yaml`) —
tune that one file if driving feels too twitchy or too sluggish;
changing it there affects both control surfaces at once.

### Arm

**The arm will not move until every joint is individually
calibrated.** This isn't a fault condition — it's how the arm
establishes where its joints actually are, since the steppers have no
absolute position sensor of their own. It calibrates all 5 joints
automatically on startup; the web GUI also lets you re-calibrate
individually.

**Web GUI, arm panel:**

| Control | Effect |
|---|---|
| `E-STOP` | Immediately stops all 5 joints (a fast, controlled deceleration, not an instant freeze) and blocks any further movement until cleared. **Does not de-energize the drivers** — see the callout below before assuming that's a bug |
| `CLEAR E-STOP` | Releases the e-stop, allowing movement again |
| 5 sliders | Direct per-joint position (motor steps from the calibrated center — J1/J3 ±150°, J2/J4 ±100°, J5 ±170°; each slider's own range matches its joint's real operational limit, and is enforced again on the firmware side regardless of what the slider allows) |
| `ENABLE DRIVERS` / `DISABLE DRIVERS (FREE-SPIN)` | Single toggle — energize/de-energize all 5 joint motors. Label and color both follow the arm's own actual current state, not which one you last clicked, same as the `DRIVERS` line in the telemetry panel below |
| `CALIBRATE J1`–`CALIBRATE J5` | Re-calibrate one joint on its own, leaving the other four alone |
| `CALIBRATE ALL 5` | Full re-calibration sequence, same as what runs automatically at startup |
| `INITIAL POSITION` | Move to the arm's predefined starting pose |
| `TRANSPORT POSITION` | Move to a compact pose safe for driving/moving the rover |
| `SERVICE POSITION` | Move to a predefined pose for servicing/accessing the arm |

A status line under those buttons shows the result of whichever one
you last pressed. Each joint's position in the telemetry panel is
marked ✓ or ✗ for calibrated/not, and the panel's own `DRIVERS` and
`E-STOP` rows show the arm's actual current state — driven by the arm
itself, not by which button you last clicked, so both stay correct
even after a page reload or if someone else triggered a change.

**All three preset buttons currently move to the same pose** (every
joint at its own true center) — distinct, genuinely useful poses for
each are still pending real-world calibration. They'll diverge once
that's done; there's nothing to configure on your end for this.

**The emergency stop does not cut power to the joint motors.** This is
deliberate, not an oversight: the arm is gravity-loaded, and cutting
power mid-motion risks it dropping under its own weight rather than
holding position — judged the worse outcome. `E-STOP` halts movement
quickly but leaves the drivers holding the arm exactly where it
stopped; `DISABLE DRIVERS (FREE-SPIN)` above is the separate control
for actually de-energizing the joints, and doing that with the arm
unsupported will let it fall.

**Xbox controller** (press LB until the controller is in ARM mode):
left stick → joints 1/2, right stick → joints 3/4, either trigger →
joint 5. This jogs continuously from the current position while the
stick is deflected, rather than setting an absolute target. The e-stop
and preset-position buttons above are web-GUI-only for now — there's
no controller shortcut for either yet.

**MoveIt2** (only if launched with `use_moveit:=true`): plan and
execute collision-aware motion by dragging an interactive marker in
RViz rather than commanding individual joints. See README's "Arm
motion planning" section for the full walkthrough — this is the one
piece of arm control this manual doesn't cover in detail, since it's
closer to a development tool than a routine operating control.

### Mast

**Web GUI, mast panel:** two sliders/readouts for head yaw (±170°) and
pitch (±180°) — absolute position, not a jog — `ERECT (SERVICE)` and
`STOW (TRANSPORT)` for the lift, `CLOSE DRIVER (ENABLE)` /
`OPEN DRIVER (DISABLE)` for the yaw/pitch drivers, plus `RETURN HOME`
(send the head to 0°/0°) and `TRANSPORT POSITION` (send it to
whatever's configured in `mast_topology.yaml`'s
`transport_head_yaw_deg`/`transport_head_pitch_deg` — not necessarily
the same as 0°/0°, and a real, bench-tunable placeholder until an
actual safe transport orientation is known). Return Home and Transport
Position deliberately don't touch the lift by themselves — sequencing
them with Stow is up to you (e.g. re-center the head first, so it
isn't wherever it last happened to be pointed while the lift lowers).

**Calibration itself now includes a drive back to center, not just
finding the limit switch.** Each axis seeks its switch (mounted at
that axis's extreme — -170° yaw, -180° pitch) the same way it always
has, but rather than calling that position "home," the mast now drives
from there back to 0°/0° first, *then* disables its own drivers.
That's what actually establishes home — the centered position, not the
switch itself. Once it's done, the yaw/pitch sliders won't do anything
until you press `CLOSE DRIVER (ENABLE)` — the telemetry panel's
`DRIVER` line shows
`ENABLED`/`DISABLED` so you can tell at a glance whether that's why
nothing's moving.

**The mast also runs a cooling fan automatically**, entirely against
its own `TEMP` reading — there's nothing to control here, just the
`FAN` telemetry line showing its current speed (or `OFF`). See
[Reading the telemetry](#5-reading-the-telemetry) below for how the
on/off thresholds work.

**Xbox controller** (LB until in MAST mode): right stick sets head
yaw/pitch directly (proportional to how far you push it, not a jog —
center the stick to return to center), **A** erects the mast to its
service position, **B** stows it back down. No button held = the lift
just holds wherever it currently is. There's no controller shortcut
for Return Home, Transport Position, or the driver enable toggle — use
the web GUI for those.

The mast's yaw/pitch axes calibrate automatically on startup, the same
way the arm's do — but unlike the arm, there's currently no per-axis,
on-demand re-calibration button for the mast specifically; calibration
only runs as a single all-axes sequence, automatically, at boot.

### Microscope

**Web GUI, microscope panel** (also at the standalone `/microscope`
page):

| Control | Effect |
|---|---|
| Focus/zoom slider | Direct position (motor steps) |
| LED brightness slider | Displayed as 0.00V–5.00V (still driven by plain PWM under the hood, 0-255 duty cycle — the display shows its volt-equivalent rather than the raw count, since there's no actual DAC or true analog output) |
| `LED ON` / `LED OFF` | Set the slider straight to full brightness (5.00V) or off (0.00V) — two separate buttons, not a toggle; the slider itself stays in sync either way it's driven |
| `CLOSE DRIVER (ENABLE)` / `OPEN DRIVER (DISABLE)` | Energize/de-energize the focus stepper — starts disabled at boot |
| `OPEN COVER` / `CLOSE COVER` | Two separate buttons (not one toggle that relabels itself) — click either any time; the cover's actual current state is shown in the telemetry panel's own `COVER` field |
| `TAKE SNAPSHOT` | Save the current camera frame to disk |
| `START RECORDING` / `STOP RECORDING` | Toggle video recording |
| `RECORD 1`/`2`/`3` + `GO TO 1`/`2`/`3` | Save the current focus position as a preset, or jump back to a saved one |

**The LED and cover no longer turn themselves off/closed if the
connection drops.** This used to happen automatically within about a
second of losing the link — it doesn't anymore, at the user's own
request. If you leave the LED on or the cover open and then lose
connection to the rover, they'll stay exactly as you left them,
indefinitely, until you reconnect and change them yourself. Worth
remembering before walking away mid-session.

The focus driver has to be explicitly enabled before the slider does
anything — it starts disabled every boot, on purpose, so nothing
drives against a mechanical stop before you're actually looking at the
live image. Presets are a browser-only convenience — they reset if you
reload the page, they're not saved anywhere permanent.

**Xbox controller** (LB until in MICROSCOPE mode): left stick Y jogs
focus/zoom, right trigger sets LED brightness, **A** toggles the lens
cover. There's no controller shortcut for enabling the focus driver,
snapshot, recording, or presets — use the web GUI for those.

### Antenna

The high-gain-antenna gimbal — azimuth (G1) and elevation (G2) — for
pointing the antenna disk. Modeled on the real Mars Exploration Rover
HGA gimbal; see README's "Antenna gimbal" section if you want the full
story behind the range numbers.

**Web GUI, antenna panel:** two sliders — azimuth (15°–285°) and
elevation (0°–180°), real operational limits, not arbitrary round
numbers — plus `CLOSE DRIVER (ENABLE)` / `OPEN DRIVER (DISABLE)`.
Unlike the microscope's driver toggle, the antenna's drivers actually
start *enabled* (homing needs them energized) — what you're really
waiting on after homing is `homed` going true, not the enable state
itself; the sliders simply won't do anything until both are ready.

**Xbox controller** (LB until in ANTENNA mode): left stick jogs
azimuth (X) and elevation (Y) continuously from the current position,
the same jog-style control the arm and microscope use — not an
absolute-position mapping the way the mast's right stick works. That's
deliberate: the antenna's operational range isn't centered around 0°
the way the mast's is, so an absolute mapping would feel much less
natural here.

### Navigation

Building a map and driving autonomously against it are both real
capabilities here, but they're closer to development/field-setup
tasks than routine daily operation, so this manual keeps it brief —
see README's "Navigation" section for the complete picture.

**Building a map:**
```bash
ros2 launch rover_bringup bringup.launch.py use_slam:=true
# drive the rover around manually (Xbox or web GUI) until the map looks complete
ros2 run nav2_map_server map_saver_cli -f ~/mars_rover_ws/src/rover_navigation/maps/my_map
```

**Driving autonomously against a saved map:**
```bash
ros2 launch rover_bringup bringup.launch.py use_navigation:=true nav_map:=/path/to/my_map.yaml
```
From there, autonomous goals are normally sent through RViz's "2D Goal
Pose" tool, or for a GPS coordinate specifically:
```bash
ros2 run rover_navigation gps_goal.py <latitude> <longitude>
```

---

## 5. Reading the telemetry

The web GUI's right-hand panel shows live status for every subsystem.
A few things worth knowing about what you're looking at:

- **Board status lamps, three states**: green means connected and
  receiving valid frames; **amber means the serial link is open but
  producing bad/unrecognized data** (the lamp's own meta text shows a
  "bad" count alongside the receive count when this is happening) —
  worth treating as a real problem, not a lesser version of green,
  since it usually means the port opened successfully but is talking
  to the wrong thing entirely (see `docs/INSTALL.md`'s troubleshooting
  table for the most common cause); red means the serial link is down
  or erroring outright. Check `docs/INSTALL.md`'s troubleshooting
  table if one won't go plain green.
- **`SUPPLY`** on arm/mast/antenna panels is the main battery
  voltage, read from each board's own voltage sensor — a real,
  independent reading per board, not one shared value. Worth a glance
  before a long session. **The base panel shows two separate
  readings instead of one**: **`DRIVE SUPPLY`** and **`STEER
  SUPPLY`**, from two independent voltage sensors on that board -
  each covers only its own rail (drive motors, steering servos), so
  the two can genuinely disagree if one rail sees more voltage drop
  under load than the other; reading the same value on both is
  expected, not a sign one sensor is redundant, if both rails happen
  to share a single battery in your build. The power panel's own
  **`BATTERY 1`**/
  **`BATTERY 2`** readings are related but distinct — see that
  panel's own bullet below.
- **`TEMP`** on base/arm/mast/antenna/microscope panels is that
  board's own enclosure temperature from a DS18B20, not ambient air —
  it's whatever's near wherever the sensor is actually mounted.
  Reads **`N/A`** if that board's sensor didn't respond on its most
  recent read — checked fresh continuously, not just once at boot, so
  a temporarily disconnected sensor recovers on its own once
  reconnected. Not a fault in normal operation, since none of these
  boards' actual jobs depend on it, but worth checking `docs/INSTALL.md`'s
  troubleshooting table if you're specifically trying to get it
  working. The power panel's own **`COMPUTER TEMP`** is a separate
  reading of a different thing entirely — see below.
- **`FAN`** on base/arm/mast/antenna/microscope panels shows that
  board's own cooling fan's current speed as a percentage, or
  **`OFF`** at 0% — entirely automatic, driven by that same panel's
  own `TEMP` reading, with no manual control anywhere in this manual
  because there isn't one to give, on any of these five panels or the
  power panel's own fan. Don't expect it to track ambient conditions
  moment-to-moment: it only turns on above a threshold, ramps with
  temperature above that, and turns back off at a *lower* threshold
  than it turned on at (intentional hysteresis, avoiding rapid on/off
  cycling right at one boundary) — a fan reading `0%` on a board that
  doesn't feel especially warm is expected, not evidence of a fault.
- **The power panel** is read-only, like every field on it — there's
  nothing to click or command here, only telemetry. **`BATTERY 1`**/
  **`BATTERY 2`** each show that battery's own voltage *and* current
  together (e.g. "24.20V / 4.50A") — independent readings from that
  battery's own sensor, not a shared value between the two.
  **`COMPUTER TEMP`** and this panel's own **`FAN`** work exactly
  like every other panel's `TEMP`/`FAN` pair above, just monitoring
  and cooling the onboard computer
  specifically rather than a board enclosure.
- **`HOMED`** (arm) and the per-joint ✓/✗ marks: whether calibration
  has completed. Movement commands are silently ignored while this
  reads false — that's expected, see [Arm](#arm).
- Position readouts (arm joint positions, mast yaw/pitch, microscope
  focus) are in raw motor steps or decidegrees, not real-world units —
  useful for confirming something is actually moving in response to a
  command, less useful as an absolute physical measurement without
  the calibration constants in `README.md`.

---

## 6. Troubleshooting

This is the short, operator-facing version — for real debugging depth
(wiring, firmware internals, protocol-level issues), `docs/INSTALL.md`
has a much longer troubleshooting table.

| Symptom | Likely cause | What to do |
|---|---|---|
| Nothing responds to the controller | RB not held, or controller in the wrong subsystem mode | Confirm RB is held continuously; press LB to check/cycle mode |
| Arm/mast won't move | Not calibrated yet | Check `HOMED`/per-joint ✓ in telemetry; wait for or re-trigger calibration |
| A board status lamp is red | Serial link down | Check the physical USB connection; see INSTALL.md's troubleshooting table |
| Rover drives but steering seems off | Servo calibration not bench-tuned for your actual hardware | See README's "Explicit assumptions" — steering calibration is a real, expected tuning step, not necessarily a bug |
| Microscope slider does nothing | Focus driver not enabled | Web GUI: `CLOSE DRIVER (ENABLE)` |
| Antenna sliders do nothing | Not homed yet, or drivers explicitly disabled | Check `HOMED`/`DRIVER` in antenna telemetry; wait for homing or press `CLOSE DRIVER (ENABLE)` |
| Mast yaw/pitch sliders do nothing, but lift buttons work fine | Head drivers not enabled - likely just finished its calibration sequence, which disables them on purpose | Check the `DRIVER` line in mast telemetry; Web GUI: `CLOSE DRIVER (ENABLE)` |
| Everything stopped and won't restart | STOP mode is latched | Press **X** on the controller, or the `ACKERMANN`/`POINT-TURN` button in the web GUI |

If none of this covers it, the underlying system is almost certainly
still running fine — `docs/INSTALL.md`'s troubleshooting table and
`README.md`'s "Known gaps" section are the next places to look before
assuming something's broken.

---

## 7. Quick reference

**Launch:**
```bash
ros2 launch rover_bringup bringup.launch.py                          # everyday driving
ros2 launch rover_bringup bringup.launch.py use_slam:=true            # build a map
ros2 launch rover_bringup bringup.launch.py use_navigation:=true nav_map:=<path>   # autonomous
ros2 launch rover_bringup bringup.launch.py use_moveit:=true          # arm motion planning
```

**Web GUI:** `http://<rover-host>:8080/` (dashboard), `/microscope`
(camera-focused view).

**Xbox controller, every mode:** hold **RB** (deadman switch), **LB**
cycles DRIVE → ARM → MAST → MICROSCOPE → ANTENNA → DRIVE.

| Mode | Left stick | Right stick | Triggers | A | B | X | Y |
|---|---|---|---|---|---|---|---|
| DRIVE | throttle / turn | — | — | — | — | toggle ACKERMANN/POINT-TURN | force STOP |
| ARM | joints 1/2 | joints 3/4 | joint 5 | — | — | — | — |
| MAST | — | yaw / pitch | — | erect | stow | — | — |
| MICROSCOPE | focus/zoom | — | LED (right only) | toggle cover | — | — | — |
| ANTENNA | azimuth/elevation | — | — | — | — | — | — |

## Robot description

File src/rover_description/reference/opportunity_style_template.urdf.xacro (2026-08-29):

<?xml version="1.0"?>
<robot xmlns:xacro="http://ros.org/wiki/xacro" name="mars_opportunity_rover">

  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

  <xacro:include filename="$(find rover_description)/urdf/common.xacro"/>

  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

  <xacro:property name="scale_x" value="0.68"/>
  <xacro:property name="scale_y" value="0.68"/>
  <xacro:property name="scale_z" value="0.68"/>

  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

  <xacro:property name="body_box" value="package://rover_description/meshes/body_box.stl"/>

  <xacro:property name="head_j2" value="package://rover_description/meshes/head_j2.stl"/>
  <xacro:property name="head_j3" value="package://rover_description/meshes/head_j3.stl"/>

  <xacro:property name="front_left_panel" value="package://rover_description/meshes/front_left_panel.stl"/>
  <xacro:property name="rear_left_panel" value="package://rover_description/meshes/rear_left_panel.stl"/>
  <xacro:property name="front_right_panel" value="package://rover_description/meshes/front_right_panel.stl"/>
  <xacro:property name="rear_right_panel" value="package://rover_description/meshes/rear_right_panel.stl"/>
  <xacro:property name="rear_middle_panel" value="package://rover_description/meshes/rear_middle_panel.stl"/>

  <xacro:property name="arm_j1" value="package://rover_description/meshes/arm_j1.stl"/>
  <xacro:property name="arm_j2" value="package://rover_description/meshes/arm_j2.stl"/>
  <xacro:property name="arm_j3" value="package://rover_description/meshes/arm_j3.stl"/>
  <xacro:property name="arm_j4" value="package://rover_description/meshes/arm_j4.stl"/>
  <xacro:property name="arm_j5" value="package://rover_description/meshes/arm_j5.stl"/>

  <xacro:property name="left_differential" value="package://rover_description/meshes/left_differential.stl"/>
  <xacro:property name="left_bogie" value="package://rover_description/meshes/left_bogie.stl"/>
  <xacro:property name="front_left_steering" value="package://rover_description/meshes/front_left_steering.stl"/>
  <xacro:property name="front_left_wheel" value="package://rover_description/meshes/front_left_wheel.stl"/>
  <xacro:property name="middle_left_wheel" value="package://rover_description/meshes/middle_left_wheel.stl"/>
  <xacro:property name="rear_left_steering" value="package://rover_description/meshes/rear_left_steering.stl"/>
  <xacro:property name="rear_left_wheel" value="package://rover_description/meshes/rear_left_wheel.stl"/>

  <xacro:property name="right_differential" value="package://rover_description/meshes/right_differential.stl"/>
  <xacro:property name="right_bogie" value="package://rover_description/meshes/right_bogie.stl"/>
  <xacro:property name="front_right_steering" value="package://rover_description/meshes/front_right_steering.stl"/>
  <xacro:property name="front_right_wheel" value="package://rover_description/meshes/front_right_wheel.stl"/>
  <xacro:property name="middle_right_wheel" value="package://rover_description/meshes/middle_right_wheel.stl"/>
  <xacro:property name="rear_right_steering" value="package://rover_description/meshes/rear_right_steering.stl"/>
  <xacro:property name="rear_right_wheel" value="package://rover_description/meshes/rear_right_wheel.stl"/>

  <xacro:property name="ant_j1" value="package://rover_description/meshes/ant_j1.stl"/>
  <xacro:property name="ant_j2" value="package://rover_description/meshes/ant_j2.stl"/>

  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
  <xacro:property name="encoder_cpr" value="1024"/>  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
  <xacro:property name="wheel_inertia" value="0.02"/>

  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
  <link name="base_link"/>

  <joint name="base_to_body_box" type="fixed">
    <parent link="base_link"/>
    <child link="body_box_link"/>
    <origin xyz="0 0 0" rpy="0 0 0"/>
  </joint>

  <link name="body_box_link">
    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
    <inertial>
      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
      <origin xyz="0 0 0"/>
      <mass value="14.0"/>
      <xacro:box_inertia mass="14.0" x="0.62" y="0.36" z="0.16"/>
    </inertial>
  </link>

  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

  <joint name="head_j2_joint" type="revolute">
    <parent link="body_box_link"/>
    <child link="head_j2_link"/>
    <origin xyz="0.24 0 0" rpy="0 0 0"/>
    <axis xyz="0 0 1"/>
    <limit lower="-1.0" upper="1.0" effort="10" velocity="1.0"/>
  </joint>

  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

  <link name="head_j2_link">
    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
    <inertial>
      <mass value="0.3"/>
      <xacro:box_inertia mass="0.3" x="0.08" y="0.08" z="0.08"/>
    </inertial>
  </link>

  <joint name="head_j3_joint" type="revolute">
    <parent link="head_j2_link"/>
    <child link="head_j3_link"/>
    <origin xyz="0 0 0.37" rpy="0 0 0"/>
    <axis xyz="0 1 0"/>
    <limit lower="-1.0" upper="1.0" effort="4" velocity="1.0"/>
  </joint>

  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

  <link name="head_j3_link">
    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
    <inertial>
      <mass value="0.2"/>
      <xacro:box_inertia mass="0.2" x="0.06" y="0.06" z="0.06"/>
    </inertial>
  </link>

  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

  <joint name="left_differential_joint" type="revolute">
    <parent link="body_box_link"/>
    <child link="left_differential_link"/>
    <origin xyz="0.09 0 -0.265" rpy="0 0 0"/>
    <axis xyz="0 1 0"/>
    <limit lower="-0.2" upper="0.2" effort="10" velocity="1.0"/>
  </joint>

  <link name="left_differential_link">
    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
    <inertial>
      <mass value="0.5"/>
      <xacro:box_inertia mass="0.5" x="0.1" y="0.1" z="0.1"/>
    </inertial>
  </link>

  <joint name="front_left_steering_joint" type="revolute">
    <parent link="left_differential_link"/>
    <child link="front_left_steering_link"/>
    <origin xyz="0.315 0.26 -0.14" rpy="0 0 0"/>
    <axis xyz="0 0 1"/>
    <limit lower="-0.3" upper="0.3" effort="10" velocity="1.0"/>
  </joint>

  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

  <link name="front_left_steering_link">
    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
    <inertial>
      <mass value="0.3"/>
      <xacro:box_inertia mass="0.3" x="0.06" y="0.06" z="0.06"/>
    </inertial>
  </link>

  <joint name="front_left_wheel_joint" type="continuous">
    <parent link="front_left_steering_link"/>
    <child link="front_left_wheel_link"/>
    <origin xyz="0 0.045 -0.033" rpy="0 0 0"/>
    <axis xyz="0 1 0"/>
  </joint>

  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

  <link name="front_left_wheel_link">
    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
    <inertial>
      <mass value="1.1"/>
      <xacro:cylinder_inertia mass="1.1" radius="0.09" length="0.06"/>
    </inertial>
  </link>

  <joint name="left_bogie_joint" type="revolute">
    <parent link="left_differential_link"/>
    <child link="left_bogie_link"/>
    <origin xyz="-0.265 0.195 -0.041" rpy="0 0 0"/>
    <axis xyz="0 1 0"/>
    <limit lower="-0.3" upper="0.3" effort="10" velocity="1.0"/>
  </joint>

  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

  <link name="left_bogie_link">
    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
    <inertial>
      <mass value="0.6"/>
      <xacro:box_inertia mass="0.6" x="0.15" y="0.08" z="0.08"/>
    </inertial>
  </link>

  <joint name="middle_left_wheel_joint" type="continuous">
    <parent link="left_bogie_link"/>
    <child link="middle_left_wheel_link"/>
    <origin xyz="0.178 0.06 -0.13" rpy="0 0 0"/>
    <axis xyz="0 1 0"/>
  </joint>

  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

  <link name="middle_left_wheel_link">
    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
    <inertial>
      <mass value="1.1"/>
      <xacro:cylinder_inertia mass="1.1" radius="0.09" length="0.06"/>
    </inertial>
  </link>

  <joint name="rear_left_steering_joint" type="revolute">
    <parent link="left_bogie_link"/>
    <child link="rear_left_steering_link"/>
    <origin xyz="-0.203 0.09 -0.1" rpy="0 0 0"/>
    <axis xyz="0 0 1"/>
    <limit lower="-0.3" upper="0.3" effort="10" velocity="1.0"/>
  </joint>

  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

  <link name="rear_left_steering_link">
    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
    <inertial>
      <mass value="0.3"/>
      <xacro:box_inertia mass="0.3" x="0.06" y="0.06" z="0.06"/>
    </inertial>
  </link>

  <joint name="rear_left_wheel_joint" type="continuous">
    <parent link="rear_left_steering_link"/>
    <child link="rear_left_wheel_link"/>
    <origin xyz="0 0.048 -0.025" rpy="0 0 0"/>
    <axis xyz="0 1 0"/>
  </joint>

  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

  <link name="rear_left_wheel_link">
    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
    <inertial>
      <mass value="1.1"/>
      <xacro:cylinder_inertia mass="1.1" radius="0.09" length="0.06"/>
    </inertial>
  </link>

  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

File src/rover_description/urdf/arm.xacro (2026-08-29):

<?xml version="1.0"?>
<robot xmlns:xacro="http://www.ros.org/wiki/xacro">

  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
  <xacro:property name="link1_len" value="0.10"/>
  <xacro:property name="link2_len" value="0.22"/>
  <xacro:property name="link3_len" value="0.20"/>
  <xacro:property name="link4_len" value="0.09"/>
  <xacro:property name="link5_len" value="0.07"/>
  <xacro:property name="arm_link_radius" value="0.03"/>
  <xacro:property name="arm_link_mass" value="0.6"/>

  <xacro:macro name="arm_segment" params="name length radius:=${arm_link_radius} mass:=${arm_link_mass}">
    <link name="${name}_link">
      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
      <inertial>
        <origin xyz="0 0 ${length/2.0}" rpy="0 0 0"/>
        <mass value="${mass}"/>
        <xacro:cylinder_inertia mass="${mass}" radius="${radius}" length="${length}"/>
      </inertial>
    </link>
  </xacro:macro>

  <joint name="chassis_to_arm_base" type="fixed">
    <parent link="chassis_link"/>
    <child link="arm_base_link"/>
    <origin xyz="${wheelbase_front + 0.05} 0 ${chassis_height/2.0}" rpy="0 0 0"/>
  </joint>
  <link name="arm_base_link">
    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
    <inertial><mass value="0.4"/><xacro:cylinder_inertia mass="0.4" radius="0.04" length="0.03"/></inertial>
  </link>

  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
  <xacro:arm_segment name="j1" length="${link1_len}"/>
  <joint name="shoulder_yaw" type="revolute">
    <parent link="arm_base_link"/>
    <child link="j1_link"/>
    <origin xyz="0 0 0.015" rpy="0 0 0"/>
    <axis xyz="0 0 1"/>
    <limit lower="${-150.0*3.14159265/180.0}" upper="${150.0*3.14159265/180.0}" effort="8.0" velocity="0.033"/>
  </joint>

  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
  <xacro:arm_segment name="j2" length="${link2_len}"/>
  <joint name="shoulder_pitch" type="revolute">
    <parent link="j1_link"/>
    <child link="j2_link"/>
    <origin xyz="0 0 ${link1_len}" rpy="0 0 0"/>
    <axis xyz="0 1 0"/>
    <limit lower="${-100.0*3.14159265/180.0}" upper="${100.0*3.14159265/180.0}" effort="12.0" velocity="0.033"/>
  </joint>

  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
  <xacro:arm_segment name="j3" length="${link3_len}"/>
  <joint name="elbow_pitch" type="revolute">
    <parent link="j2_link"/>
    <child link="j3_link"/>
    <origin xyz="0 0 ${link2_len}" rpy="0 0 0"/>
    <axis xyz="0 1 0"/>
    <limit lower="${-150.0*3.14159265/180.0}" upper="${150.0*3.14159265/180.0}" effort="8.0" velocity="0.033"/>
  </joint>

  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
  <xacro:arm_segment name="j4" length="${link4_len}" radius="0.022" mass="0.3"/>
  <joint name="wrist_pitch" type="revolute">
    <parent link="j3_link"/>
    <child link="j4_link"/>
    <origin xyz="0 0 ${link3_len}" rpy="0 0 0"/>
    <axis xyz="0 1 0"/>
    <limit lower="${-100.0*3.14159265/180.0}" upper="${100.0*3.14159265/180.0}" effort="4.0" velocity="0.033"/>
  </joint>

  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
  <xacro:arm_segment name="j5" length="${link5_len}" radius="0.02" mass="0.2"/>
  <joint name="wrist_roll" type="revolute">
    <parent link="j4_link"/>
    <child link="j5_link"/>
    <origin xyz="0 0 ${link4_len}" rpy="0 0 0"/>
    <axis xyz="0 0 1"/>
    <limit lower="${-170.0*3.14159265/180.0}" upper="${170.0*3.14159265/180.0}" effort="3.0" velocity="0.033"/>
  </joint>

  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
  <link name="microscope_link">
    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
    <inertial>
      <mass value="0.15"/>
      <xacro:box_inertia mass="0.15" x="0.05" y="0.04" z="0.06"/>
    </inertial>
  </link>

  <joint name="microscope_focus_joint" type="prismatic">
    <parent link="j5_link"/>
    <child link="microscope_link"/>
    <origin xyz="0 0 ${link5_len}" rpy="0 0 0"/>
    <axis xyz="0 0 1"/>
    <limit lower="0.0" upper="0.015" effort="0.5" velocity="0.02"/>
  </joint>

  <link name="microscope_optical_frame"/>
  <joint name="microscope_optical_joint" type="fixed">
    <parent link="microscope_link"/>
    <child link="microscope_optical_frame"/>
    <origin xyz="0 0 0.03" rpy="${-3.14159265/2.0} 0 ${-3.14159265/2.0}"/>
  </joint>

</robot>

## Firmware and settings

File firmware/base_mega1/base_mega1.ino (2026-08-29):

// base_mega1.ino
//
// Arduino Mega #1 - rover base controller.
//   * 6x 12V/83RPM DFRobot gear motors, all driven; only the two fixed
//     middle wheels (ML, MR) carry quadrature encoders - see the
//     encoder section below for why
//   * 3x DFRobot DRI0002 Dual H-Bridge V1.4 motor drivers, L298N-based
//     (6 motor channels total)
//   * 4x 40kg steering servos (front-left/right, rear-left/right),
//     driven via a PCA9685 16-channel PWM driver module over I2C
//     (address 0x40, its factory default - see the wiring note below
//     for why this project deliberately does NOT jumper it to
//     anything else) rather than direct Mega pins. Channels 0-3 -> FL/FR/RL/RR.
//     ServoEasing doesn't work with a PCA9685 (it's built for direct-
//     pin, standard-Servo-library-style control, not an I2C PWM chip),
//     so smoothed movement is reimplemented here as a small,
//     non-blocking millis()-based ramp (updateSteerEasing()) toward
//     each corner's latest commanded position, rather than dropped -
//     this project has consistently valued smoothed servo motion
//     (mast lift, microscope cover, and this exact axis previously),
//     and there's no reason a different output mechanism should mean
//     losing it. A genuine side effect worth noting: since nothing
//     else on this board used ServoEasing, this removes that GPL-3.0
//     dependency here entirely - see the journal for the history if
//     that matters (docs/journal.md).
//   * DS18B20 temperature sensor (board/enclosure temperature, not
//     ambient air - it's whatever's near wherever it's actually
//     mounted), TO-92 package, 1-Wire on a single digital data pin
//     (kDs18b20DataPin) rather than I2C. Previously pin 20 (this
//     Mega's own SDA), moved to A4 when the PCA9685 above needed 20
//     back for genuine I2C - A4 was one of the pins the steering
//     servos vacated moving to that same PCA9685, so this reuses one
//     freed pin for another, rather than search for a third.
//     REQUIRES AN EXTERNAL 4.7k-OHM PULL-UP RESISTOR between DQ and
//     VDD - the Arduino's internal pull-ups are too weak for reliable
//     1-Wire timing; this is not optional or achievable via
//     INPUT_PULLUP. Conversion is read via a non-blocking two-phase
//     state machine (request, then check back after the datasheet's
//     worst-case ~750ms conversion time) rather than the library's own
//     default blocking `delay(750)` pattern, since blocking loop() for
//     750ms on every read would stall drive-command processing on a
//     board whose real job is real-time motor control. See the
//     temperature section further down for the full reasoning - it
//     applies identically on all five boards with this same sensor.
//   * Cooling fan via a generic N-channel MOSFET driver module (e.g.
//     IRF520-style: SIG/VCC/GND control side, V+/V- screw terminals
//     for the load) - same automatic, thermostatic design and the
//     same low-side-switch wiring caveat as mast_uno3.ino's own copy
//     of this feature (see that file's header for the full reasoning
//     on the wiring, hysteresis, and fail-toward-running-on-sensor-
//     failure choice; identical here). The one real difference: this
//     board is a Mega with pins to spare, so kFanPwmPin (44) gets
//     genuine hardware PWM via analogWrite() - no need for the
//     mast's software-PWM workaround, which existed only because that
//     Uno's entire hardware-PWM budget was already spent.
//
// DRI0002 interface (per DFRobot's own datasheet/wiki): each of its two
// channels exposes just ONE direction pin (Mx) plus one PWM/speed pin
// (Ex) - not a pair of direction pins as some other dual-H-bridge
// boards use. Documented convention: Mx = LOW drives that channel
// "forward". That's only meaningful relative to which wire landed on
// the +/- screw terminal, so confirm actual wheel rotation direction
// on the bench and flip the sign in setWheelThrottle() below (not by
// rewiring the terminal) if a wheel spins the wrong way.
//
// Wiring note: DRI0002 has a logic-supply jumper - shorted means the
// L298N's logic rail is powered from the same supply as the motors,
// which the datasheet says is only safe below 12V. Our motors are
// rated exactly at 12V, right at that boundary, so the safer default
// is to leave the jumper OPEN and power the driver's logic pins from
// the Arduino's own 5V rail instead (shared ground required either
// way). Confirm against the specific V1.4 silkscreen before wiring.
//
// Wiring note for the servos: the PCA9685 module's V+ screw terminal
// is a dedicated servo power rail, separate from its VCC (logic-only)
// pin - wire V+ to a separate, adequately-rated 5-6V supply (four
// 40kg-class digital servos can draw well beyond what the Mega's
// onboard 5V regulator or a USB-supplied 5V can safely deliver),
// sharing ground with the Arduino, never from the Mega's own 5V pin.
// This is exactly the dedicated rail a previous, direct-pin version of
// this same steering setup didn't have, and had to call out as a gap
// to fill separately - the PCA9685 fills it natively.
//
// I2C wiring: SDA -> Mega pin 20, SCL -> Mega pin 21 (the Mega's
// dedicated hardware I2C pins, not configurable - this is why the
// DS18B20 above lives on A4 now instead, having previously used pin
// 20 back when nothing else needed it). The PCA9685's I2C address is
// jumper-configurable via solder pads on the board itself, but this
// project deliberately leaves them unbridged: 0x40, the factory
// default, is used as-is - see kPca9685Address below for why (in
// short, this chip's own separate "All Call" address is a fixed 0x70
// on every unit regardless of jumpers, so 0x70 is specifically the
// one address NOT to jumper a device to, per the chip's own datasheet
// and Adafruit's own guidance - an earlier version of this comment
// got that backwards).
//
// Talks to the ROS 2 `rover_base` bridge node over USB-serial using the
// shared RoverProtocol framing (see firmware/common/RoverProtocol).
//
// Requires "Adafruit PWM Servo Driver Library" (Library Manager, by
// Adafruit) for the PCA9685, "OneWire" (by Paul Stoffregen) and
// "DallasTemperature" (by Miles Burton) for the temperature sensor -
// see the LICENSING NOTE below for how these differ from each other
// and from the rest of this project.
//
// LICENSING NOTE: this file no longer uses ServoEasing (GPL-3.0) -
// moving the steering servos to the PCA9685 removed that dependency
// entirely, since nothing else on this board used it. What remains:
// "Adafruit PWM Servo Driver Library" is BSD licensed (confirmed
// against the library's own source headers, not just a third-party
// index - some of those show "NOASSERTION" for this library, which is
// a known quirk of automated license detection against a non-standard
// header format, not an actual absence of a license). BSD is
// permissive, similar in spirit to this project's own Apache-2.0,
// though a technically distinct license family - worth a line here
// for completeness even though it's a materially smaller concern than
// GPL/LGPL copyleft. DallasTemperature is LGPL-2.1, not MIT, not BSD,
// and not GPL-3.0 - see base_mega1.ino's earlier version of this same
// note (now in docs/journal.md's history) for the fuller reasoning on
// why that's worth tracking as its own, distinct consideration.

#include <Wire.h>
#include <Adafruit_PWMServoDriver.h>
#include <OneWire.h>
#include <DallasTemperature.h>
#include <RoverProtocol.h>

// ---------------------------------------------------------------- pins ---
// Wheel order used for driving/steering below: FL, FR, ML, MR, RL, RR
constexpr uint8_t kNumWheels = 6;
constexpr uint8_t kNumSteer = 4;  // FL, FR, RL, RR

// Only ML and MR are physically encoded - see rover_base/odometry.py's
// module docstring for the full reasoning: they're the only pair whose
// rolling axis never changes with corner steering, so they're the only
// pair standard differential-drive wheel odometry actually needs.
// Wiring individual encoders on the 4 steerable corners would add
// hardware complexity (and firmware complexity - see the PCINT note
// this used to require for RL/RR before they were removed) for data
// nothing consumes.
constexpr uint8_t kNumEncoders = 2;  // ML, MR
constexpr uint8_t kEncA[kNumEncoders] = {18, 19};   // ML, MR channel A
constexpr uint8_t kEncB[kNumEncoders] = {24, 25};   // ML, MR channel B
// Pins 18/19 are INT5/INT4 on the Mega - true external-interrupt-capable
// pins, so plain attachInterrupt() is enough; no PCINT/port-register
// wrangling needed (that was only required for the since-removed RL/RR
// encoders, which lived on A8/A9).

// FZ0430 voltage sensors (drive rail + steering rail, one each): a
// passive 5:1 resistive divider bringing a 0-25V input down into the
// Mega's 0-5V ADC range, signal output on one analog pin. Every
// analog pin was free before this, so A0 is an arbitrary but
// permanent choice, not one forced by pin scarcity - keep it
// consistent with arm_mega2.ino/mast_uno3.ino, which use the same
// pin for their own supply sensors.
//
// UPDATED: this board now has two FZ0430s, not one - a second unit
// added on A1, same configuration as this one (same 5:1 divider, same
// conversion math), specifically to give the drive motors' own supply
// rail and the steering servos' own supply rail independent voltage
// readings rather than one shared value covering both. This first
// sensor is now explicitly the DRIVE rail's own reading, not a
// generic "main supply" the way it was before the second unit existed
// - see kSteeringVoltageSensorPin below for the second.
constexpr uint8_t kDriveVoltageSensorPin = A0;
// Second FZ0430, steering servos' own supply rail - see the comment
// on kDriveVoltageSensorPin above for the full reasoning. Same
// configuration as the first unit, deliberately: same 5:1 divider,
// same conversion math, same wiring pattern - the only real
// difference between the two is which physical rail each is actually
// connected to.
constexpr uint8_t kSteeringVoltageSensorPin = A1;

// DS18B20 temperature sensor, 1-Wire on a single digital pin. Was the
// Mega's former I2C SDA pin (20) until the PCA9685 below needed that
// pin back for genuine I2C - moved to A4, one of the pins the
// steering servos vacated moving to that same PCA9685, rather than
// search out a third free pin.
constexpr uint8_t kDs18b20DataPin = A4;
// How often to START a new conversion cycle, milliseconds - not on
// every state frame (~20Hz) the way voltage is, since board
// temperature changes over seconds-to-minutes, not tens-of-milliseconds;
// polling that often would just be wasted bus traffic for a value
// that's the same reading, over and over.
constexpr unsigned long kTemperatureReadIntervalMs = 1000;
// Worst-case 12-bit-resolution conversion time per the DS18B20
// datasheet - how long to wait after requestTemperatures() before the
// result is actually ready. Read via a non-blocking two-phase state
// machine (see updateCachedTemperature()) rather than the library's
// own default blocking `delay(750)` pattern - see this file's header
// comment for why blocking loop() for 750ms on every read isn't
// acceptable here.
constexpr unsigned long kTemperatureConversionMs = 750;
// Sentinel sent over the wire when the sensor didn't respond on its
// most recent read - -999.9 deg C in decidegrees, comfortably outside
// the DS18B20's real -55 to +125 deg C range, so it can't be confused
// with an actual (if extreme) reading. Chosen over a separate boolean
// "temperature valid" field to avoid growing every consumer of this
// value (protocol, message, bridge node, web GUI) by one more field
// each - one clearly-impossible number carries the same information.
// Checked fresh on every read cycle (DallasTemperature's own
// DEVICE_DISCONNECTED_C, not a one-time boot check the way the BMP280
// this replaced only checked once at setup()) - a sensor that's
// disconnected and later reconnected recovers on its own next cycle,
// it doesn't need a reset.
constexpr int32_t kTemperatureInvalidDeciC = -9999;

// Cooling fan - see mast_uno3.ino for the full reasoning on every
// constant below (thermostat design, hysteresis, sensor-failure
// fail-safe); values kept identical across every board with a fan,
// same as the temperature-sensor constants above. kFanPwmPin differs
// per board only because pin availability differs per board - see
// this file's own header comment for why 44 specifically here.
constexpr uint8_t kFanPwmPin = 44;
constexpr int32_t kFanOnTempDeciC = 350;
constexpr int32_t kFanOffTempDeciC = 300;
constexpr int32_t kFanMaxTempDeciC = 500;
constexpr uint8_t kFanMinDutyPercent = 30;

// Motor driver pins: one direction pin (Mx) + one PWM/speed pin (Ex)
// per DRI0002 channel - see the file header for the M-pin convention
// and the logic-supply jumper note. Three boards x two channels each:
// board 1 -> FL,FR; board 2 -> ML,MR; board 3 -> RL,RR. All 6 wheels
// are driven regardless of which are encoded.
constexpr uint8_t kMotorPwm[kNumWheels] = {4, 5, 6, 7, 8, 9};        // Ex
constexpr uint8_t kMotorDir[kNumWheels] = {28, 29, 30, 31, 32, 33};  // Mx

// PCA9685 16-channel PWM driver, I2C - drives the 4 steering servos.
// CORRECTED from an earlier session's own mistake: 0x70 is NOT a
// normal, jumper-configurable address on this chip - it's the
// PCA9685's built-in "LED All Call" address, enabled by every unit at
// power-up regardless of A0-A5 jumper state (confirmed in the chip's
// own datasheet, and Adafruit's own FAQ explicitly warns against
// configuring a device to that same address for exactly this reason).
// This project only ever has one PCA9685, so there's no reason to
// move it off its factory default at all - 0x40, unjumpered, no
// solder pads to bridge.
constexpr uint8_t kPca9685Address = 0x40;
constexpr uint8_t kSteerChannel[kNumSteer] = {0, 1, 2, 3};  // FL,FR,RL,RR -> PCA9685 channels
// Index into the 6-wide wheel arrays that each steer channel corresponds to,
// used only for readability/debug prints.
constexpr uint8_t kSteerWheelIndex[kNumSteer] = {0, 1, 4, 5};  // FL,FR,RL,RR

Adafruit_PWMServoDriver pwm(kPca9685Address);

// Easing rate for steering, microseconds/second - a direct translation
// of the previous ServoEasing-based rate (300 deg/sec) into this
// board's own pulse-width terms, not a re-guess: at this project's
// placeholder calibration (900us neutral-to-max span for a 90 deg
// swing, i.e. ~10us/deg), 300 deg/sec times 10us/deg is ~3000us/sec,
// preserving the same "a full +-60 deg swing takes ~0.4s" feel the
// previous constant's own comment described. Same placeholder-
// pending-bench-tuning status as every other uncalibrated constant in
// this project - revisit once kServoMinUs/kServoMaxUs/kServoNeutralUs
// below are themselves bench-calibrated, since this rate was derived
// from their current placeholder values specifically.
constexpr float kSteerEaseSpeedUsPerSec = 3000.0f;

// ------------------------------------------------------------- state ---
volatile int32_t encoderTicks[kNumEncoders] = {0, 0};  // ML, MR

OneWire oneWire(kDs18b20DataPin);
DallasTemperature ds18b20(&oneWire);
enum TempReadState : int8_t { TEMP_IDLE = 0, TEMP_CONVERTING = 1 };
int8_t tempReadState = TEMP_IDLE;
unsigned long tempConversionStartMillis = 0;
int32_t cachedTemperatureDeciC = kTemperatureInvalidDeciC;
unsigned long lastTemperatureReadMillis = 0;

bool fanRunning = false;
uint8_t fanDutyPercent = 0;

// Servo neutral/travel calibration, per corner (FL, FR, RL, RR - same
// order as kSteerChannel). 40kg metal-gear servos commonly want a
// wider-than-hobby-standard pulse range, and real units - even same
// model, same batch - can vary enough in their actual center/travel
// that a single shared calibration was only ever a starting point,
// not a real bench calibration. All four start at the same
// placeholder values below on purpose - that's the safe default until
// each corner is actually bench-tested, not a mistake to fix here -
// then tune each servo's own entry independently as its real travel
// is measured, without touching the other three.
constexpr float kServoMinUs[kNumSteer] = {600.0f, 600.0f, 600.0f, 600.0f};
constexpr float kServoMaxUs[kNumSteer] = {2400.0f, 2400.0f, 2400.0f, 2400.0f};
constexpr float kServoNeutralUs[kNumSteer] = {1500.0f, 1500.0f, 1500.0f, 1500.0f};

// Custom easing state - see updateSteerEasing() below. steerTargetUs
// is where setSteerAngle() wants each corner to end up; steerCurrentUs
// is where it actually, physically is right now (in this firmware's
// own tracking - the PCA9685 has no position feedback of its own),
// ramping toward the target a little each loop() iteration rather
// than jumping there in one write().
float steerTargetUs[kNumSteer];
float steerCurrentUs[kNumSteer];
unsigned long lastSteerEaseMillis = 0;

constexpr unsigned long kWatchdogTimeoutMs = 500;
unsigned long lastCommandMillis = 0;

RoverProtocol::LineReader lineReader;
char lineBuf[RoverProtocol::kMaxLineLen];

// ---------------------------------------------------- encoder helpers ---
inline void handleEncoderEdge(uint8_t encoderIndex, bool aState, bool bState) {
  // Standard quadrature decode: on A's rising edge, B high means one
  // direction, B low means the other. (Swap the sign below if a wheel
  // reports the wrong direction on the bench - do not rewire.)
  if (aState) {
    encoderTicks[encoderIndex] += bState ? -1 : 1;
  } else {
    encoderTicks[encoderIndex] += bState ? 1 : -1;
  }
}

void isrEncML() { handleEncoderEdge(0, digitalRead(kEncA[0]), digitalRead(kEncB[0])); }
void isrEncMR() { handleEncoderEdge(1, digitalRead(kEncA[1]), digitalRead(kEncB[1])); }

// ------------------------------------------------------- motor output ---
void setWheelThrottle(uint8_t wheel, int32_t throttle) {
  throttle = constrain(throttle, -1000, 1000);
  uint8_t pwmVal = (uint8_t)(abs(throttle) * 255L / 1000L);

  // DRI0002's documented convention is Mx=LOW -> "forward"; flip this
  // comparison (not the wiring) if a wheel bench-tests backward. At
  // pwmVal == 0 no current flows regardless of the direction pin, so
  // throttle == 0 already coasts without any special-casing here.
  digitalWrite(kMotorDir[wheel], throttle < 0 ? HIGH : LOW);
  analogWrite(kMotorPwm[wheel], pwmVal);
}

void setSteerAngle(uint8_t steerIndex, float angleDeg) {
  angleDeg = constrain(angleDeg, -90.0f, 90.0f);
  float neutral = kServoNeutralUs[steerIndex];
  // Use the min-side span for negative angles and the max-side span
  // for positive ones, rather than always scaling off (max - neutral)
  // - those two spans are only equal if neutral happens to sit exactly
  // centered between min and max. A real bench-calibrated servo often
  // won't: e.g. min=600/max=2400/neutral=1450 has a 850us min-side span
  // and a 950us max-side span, not one shared 900us span either
  // direction. Using the wrong span doesn't just misreport the angle -
  // it silently shrinks the achievable range on whichever side is
  // shorter, since the final constrain() below then clips to a pulse
  // width that no longer corresponds to the actual commanded angle.
  float span = (angleDeg >= 0.0f)
      ? (kServoMaxUs[steerIndex] - neutral)
      : (neutral - kServoMinUs[steerIndex]);
  float us = neutral + (angleDeg / 90.0f) * span;
  us = constrain(us, kServoMinUs[steerIndex], kServoMaxUs[steerIndex]);
  // Just records where this corner should end up - the actual
  // movement happens incrementally in updateSteerEasing() below, not
  // here, so this function itself is effectively instantaneous no
  // matter how far the target moved.
  steerTargetUs[steerIndex] = us;
}

// Non-blocking custom easing, replacing ServoEasing's own
// startEaseTo()/timer-interrupt approach - see this file's header
// comment for why a PCA9685 needs this reimplemented rather than
// reused. Moves each corner's steerCurrentUs a little closer to its
// steerTargetUs every call, at kSteerEaseSpeedUsPerSec, and writes the
// result to the PCA9685 - called every loop() iteration for smooth,
// frequent updates, the same way ServoEasing's own interrupt-driven
// updates were effectively continuous.
void updateSteerEasing() {
  unsigned long now = millis();
  float elapsedSec = (now - lastSteerEaseMillis) / 1000.0f;
  lastSteerEaseMillis = now;
  float maxStepUs = kSteerEaseSpeedUsPerSec * elapsedSec;

  for (uint8_t i = 0; i < kNumSteer; i++) {
    float delta = steerTargetUs[i] - steerCurrentUs[i];
    if (delta > maxStepUs) {
      steerCurrentUs[i] += maxStepUs;
    } else if (delta < -maxStepUs) {
      steerCurrentUs[i] -= maxStepUs;
    } else {
      steerCurrentUs[i] = steerTargetUs[i];  // within one step - snap the remainder rather than asymptotically crawl the last fraction of a microsecond forever
    }
    pwm.writeMicroseconds(kSteerChannel[i], (uint16_t)steerCurrentUs[i]);
  }
}

void stopAllMotors() {
  for (uint8_t i = 0; i < kNumWheels; i++) setWheelThrottle(i, 0);
}
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
void loop() {
  updateCachedTemperature();
  updateFanControl();
  updateSteerEasing();

  if (lineReader.poll(Serial, lineBuf, sizeof(lineBuf))) {
    RoverProtocol::ParsedFrame frame = RoverProtocol::parseFrame(lineBuf);
    if (frame.valid) {
      if (frame.type == 'D') {
        handleDriveFrame(frame);
        sendEncoderFrame();
      } else if (frame.type == 'H') {
        lastCommandMillis = millis();
        sendEncoderFrame();
      }
    }
    // Invalid frames (bad checksum/garbage) are silently dropped; the
    // watchdog below will stop the rover if valid commands stop arriving.
  }

  if ((millis() - lastCommandMillis) > kWatchdogTimeoutMs) {
    stopAllMotors();
  }
}

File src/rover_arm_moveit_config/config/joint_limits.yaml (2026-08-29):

# Joint limits for MoveIt's trajectory time parameterization.
#
# max_velocity here matches rover_description/urdf/arm.xacro's own
# <limit velocity="..."/> values exactly - not restated independently,
# just made visible to MoveIt, which reads velocity/position limits
# from the URDF automatically but needs acceleration limits declared
# separately here since URDF has no field for them.
#
# Recomputed for the EBA-17-M planetary gearbox (120:1) - NEMA17 +
# A4988 per joint (see rover_arm/config/arm_topology.yaml). The
# firmware's own AccelStepper profile is the real, binding constraint
# (arm_mega2.ino: kMaxSpeedStepsPerSec=2000, kAccelStepsPerSec2=4000
# steps/s^2 - motor-shaft limits, independent of gear ratio); these
# values are that same motor-shaft profile converted through the new
# 384000 steps/rev (200 full steps * 1/16 microstepping * 120:1) to
# real joint-space rad/s and rad/s^2, not independently chosen. All
# five joints get the identical value now, correctly - the previous
# per-joint spread (1.5/1.8/2.0/2.5) was never grounded in anything
# joint-specific to begin with, and every joint shares the same
# motor+gearbox+firmware speed cap, so they should read the same.
# Notably slower than the old 5:1-gearing placeholder implied
# (~0.79 rad/s then vs ~0.033 rad/s now) - the real tradeoff of a
# much higher reduction ratio: more torque and precision, less speed.
joint_limits:
  shoulder_yaw:
    has_velocity_limits: true
    max_velocity: 0.033
    has_acceleration_limits: true
    max_acceleration: 0.065
  shoulder_pitch:
    has_velocity_limits: true
    max_velocity: 0.033
    has_acceleration_limits: true
    max_acceleration: 0.065
  elbow_pitch:
    has_velocity_limits: true
    max_velocity: 0.033
    has_acceleration_limits: true
    max_acceleration: 0.065
  wrist_pitch:
    has_velocity_limits: true
    max_velocity: 0.033
    has_acceleration_limits: true
    max_acceleration: 0.065
  wrist_roll:
    has_velocity_limits: true
    max_velocity: 0.033
    has_acceleration_limits: true
    max_acceleration: 0.065

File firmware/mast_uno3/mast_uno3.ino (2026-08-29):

// mast_uno3.ino
//
// Arduino Uno #3 - mast controller (previously a Mega; replaced with
// an Uno, which is why every pin below is a new assignment even where
// the function is unchanged - the Uno's usable digital range is just
// D2-D13 (D0/D1 are Serial RX/TX, needed for the host link), nothing
// like the Mega's headroom).
//   * 2x NEMA17 + TB6600 for the head's yaw/pitch axes (replaces the
//     original A4988 driver assumption), each with its own
//     calibration (limit) switch, mounted at that axis's minimum
//     (most-negative) bound - homing seeks the switch, then treats
//     that position as the axis's minimum (-170 deg yaw, -180 deg
//     pitch) rather than zero, then drives to the true zero (center
//     of travel) from there - see serviceHoming()/servicePostCalibration()
//     for the full sequence. Steppers have no absolute position
//     feedback of their own, hence needing this at all. See
//     arm_mega2.ino for the original version of the underlying
//     seek-a-switch homing pattern; mirrored here for 2 axes instead
//     of 5, with the offset-then-center step added on top.
//     TB6600's PUL/DIR inputs are functionally equivalent to
//     STEP/DIR - AccelStepper::DRIVER mode just toggles a pin for
//     each pulse either way, so kStepPin/kDirPin below work
//     unchanged. What's genuinely different: TB6600 inputs are
//     opto-isolated (PUL+/PUL-/DIR+/DIR-/ENA+/ENA-, not simple direct
//     logic pins) and its microstepping/current limit are set via DIP
//     switches on the driver itself, not firmware - kStepsPerDegYaw/
//     Pitch below need to match whatever microstepping the switches
//     are actually set to, the same as any other driver swap. Wiring
//     assumed here is the standard common-anode setup (PUL+/DIR+/
//     ENA+ tied to +5V, PUL-/DIR-/ENA- driven by the Arduino pins) -
//     if wired common-cathode instead, the enable polarity below is
//     backwards and needs flipping.
//     Added explicit enable control as part of this swap
//     (kHeadEnablePin) - the previous A4988 wiring had no enable pin
//     driven by firmware at all, relying on whatever that specific
//     breakout's floating-EN default happened to be. TB6600's
//     opto-isolated ENA input is less forgiving of being left
//     floating than that, and explicit control is worth having
//     regardless - this now commits the very last available Uno pin
//     (13), so the board's digital pin budget is fully spent: 12 of
//     12 usable pins (D2-D13) in use, none spare.
//   * 1x brushed DC lift motor that erects the mast from a horizontal
//     transport position to a vertical service position, driven
//     through an HW-039 (dual BTS7960B half-bridge) driver - replaces
//     the previous generic 2-direction-pin H-bridge. HW-039's native
//     interface is RPWM/LPWM (a separate PWM pin per direction, not
//     one shared PWM + direction-select pin), simplified here to a
//     single shared enable pin (R_EN/L_EN tied together) rather than
//     wiring both independently, to fit the Uno's tight pin budget -
//     R_IS/L_IS (current sense) are left unconnected, not needed for
//     this application.
//   * 2x limit switches bound the lift travel: stowed (horizontal/
//     transport) and erect (vertical/service) - unrelated to the new
//     yaw/pitch calibration switches above, and don't need homing:
//     the lift is a plain DC motor with no step-relative position to
//     zero, just a directly-read "which limit (if any) is currently
//     triggered" state.
//   * DS18B20 temperature sensor, TO-92, 1-Wire on a single digital
//     pin (kDs18b20DataPin = A4, reusing the Uno's former I2C SDA pin)
//     - genuinely free despite the digital pin budget above being
//     fully spent (D2-D13, 12 of 12), since A4 is a separate pin pool
//     entirely, not part of that count. See base_mega1.ino's own copy
//     of this sensor for the full reasoning (external pull-up
//     requirement, non-blocking read state machine, sentinel
//     convention); identical here, just on this Uno's own former SDA
//     pin rather than a Mega's.
//   * Cooling fan via a generic N-channel MOSFET driver module (e.g.
//     IRF520-style breakout: SIG/VCC/GND on the control side, V+/V-
//     screw terminals on the load side) - a LOW-SIDE switch, worth
//     being explicit about since it's a common wiring mix-up: the
//     fan's positive lead goes directly to the external supply
//     (V+/Vin, always on), and the MOSFET switches the fan's
//     *negative* lead (through V-/OUT) to ground - not the fan's
//     positive side the way a more intuitive high-side design might
//     suggest. VCC on the module's control header only powers its
//     own onboard status LED and can be left disconnected; only GND
//     and SIG are actually required for switching.
//
//     SIG needs a PWM-capable pin for variable speed, but the Uno's
//     entire hardware-PWM budget (D3/D5/D6/D9/D10/D11) was already
//     fully committed by the yaw/pitch/lift functions above before
//     this was added - kFanPwmPin (A2) runs a simple millis()-based
//     software PWM instead (see updateFanPwm()), which the MOSFET
//     module doesn't distinguish from hardware PWM in any way that
//     matters for a slowly-responding load like a fan.
//
//     Entirely automatic, not operator-commanded: speed is a function
//     of the DS18B20 reading above (updateFanControl()), ramping
//     between kFanOnTempDeciC and kFanMaxTempDeciC with hysteresis
//     against kFanOffTempDeciC to avoid rapid on/off cycling right at
//     the threshold. All threshold values are placeholders - bench-
//     tune once the real enclosure's actual thermal behavior is
//     known, the same as every other uncalibrated constant in this
//     project. If the temperature sensor itself isn't responding
//     (cachedTemperatureDeciC at its own sentinel), the fan defaults
//     to running rather than off - a deliberate fail-toward-cooling
//     choice: unnecessary fan noise is a minor cost, an overheating
//     board with no way to know it's overheating is a real one.
//
// Talks to the ROS 2 `rover_mast` bridge node using the shared
// RoverProtocol framing. Requires the AccelStepper library, "OneWire"
// (by Paul Stoffregen), and "DallasTemperature" (by Miles Burton) -
// see base_mega1.ino's own header comment for the DallasTemperature
// LGPL-2.1 licensing note. The fan control itself needs no additional
// library - plain digitalWrite()/millis(), the same as everything
// else in this file that isn't a stepper or 1-Wire device.

#include <AccelStepper.h>
#include <OneWire.h>
#include <DallasTemperature.h>
#include <RoverProtocol.h>

constexpr uint8_t kNumHeadAxes = 2;  // yaw, pitch
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
